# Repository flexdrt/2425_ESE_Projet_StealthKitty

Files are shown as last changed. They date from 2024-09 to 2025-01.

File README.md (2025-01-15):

# 🐱 **StealthKitty - Projet Robot Chat**  

 Logo ENSEA   
 
  

---

## 📜 **Description**  
StealthKitty est un projet de **système embarqué innovant** basé sur un **STM32**.  
🎯 **Objectif :** Développer plusieurs robots capables de se déplacer sur une table sans bordure.  

- 🐾 Un robot est désigné comme chat et doit attraper un autre robot, qui devient alors le nouveau chat.  

Ce projet est réalisé dans le cadre de la dernière année de la filière **électronique et systèmes embarqués (ESE)** de l'ENSEA.

### **Les contributeurs :**  
- 👨‍💻 **Vincent LAKHMECHE**  
- 👨‍💻 **Mohamed Rafik CHAIR**  
- 👨‍💻 **Meziane Ameur**  
- 👨‍💻 **Karim JERJOUB**

<p align="center">
  
</p>

---

## 📚 **Table des matières**
1. [📖 Contexte](#-contexte)
2. [📐 Architecture](#-architecture)  
3. [✨ Fonctionnalités](#-fonctionnalités)
4. [📚 Explication Technique](#-Explication-Technique). 
5. [🔧 Matériel utilisé](#-matériel-utilisé)  
6. [🚀 Utilisation](#-utilisation)  
7. [📄 Licence](#-licence)  

---

## 📖 **Contexte**  
Ce projet s'inscrit dans le cadre de la formation 3A à l'ENSEA.  
🎯 L'objectif est de concevoir un système embarqué complet, depuis la conception électronique jusqu'à l'implémentation logicielle.

---

## 📐 **Architecture**  
### **Schéma architectural**  


Ce schéma ne détaille pas que chaque moteur a sa propre pwm et son driver propre également.

## Explication du fonctionnement du système

1. **⚡ Alimentation principale**
   - La **batterie NiMH 7.2V 1.3Ah** alimente l'ensemble du système. Elle est connectée à des régulateurs de tension pour fournir les différentes tensions nécessaires aux composants :
     - **MP1475S** : Régulateur 5V pour alimenter les moteurs et certains capteurs.
     - **BU33SD5WG-TR** : Régulateur 3.3V pour alimenter le microcontrôleur STM32G431, l'accéléromètre et le LiDAR.

2. **🖥️ Microcontrôleur principal - STM32G431**
   - Le **STM32G431** gère toute la logique du robot et communique avec les différents composants via des bus tels que SPI, UART, I2C.
   - Il est relié à un **quartz 16 MHz** pour la gestion de l'horloge système et dispose d'un connecteur **SWD** pour la programmation et le débogage.

3. **🔍 Capteurs**
   - **Capteurs ToF** : Utilisés pour détecter les bords ou les chutes du robot.
   - **ADXL343 (Accéléromètre)** : Détecte les impacts ou les tapotements, utilisé pour détecter les collisions avec d'autres robots, et connecté au bus **SPI**.
   - **LiDAR YDLIDAR X4** : Permet de détecter les obstacles à l'aide de la communication **UART** pour transmettre les données de distance et d'angle.

4. **⚙️ Contrôle des moteurs**
   - **ZXBM5210-SP-13 (Driver de moteur)** : Utilisé pour contrôler la direction et la vitesse des moteurs à l'aide de signaux **PWM**. Le microcontrôleur STM32 contrôle les moteurs via le driver pour ajuster la vitesse et la direction du robot.

5. **🌟 Indicateurs d'état (LEDs)**
   - Les **LEDs** servent d'indicateurs pour visualiser l'état du robot, par exemple, lorsqu'il est en marche ou lorsqu'il détecte un obstacle.

### Détails des principaux outils utilisés

1. **Communication avec l'accéléromètre (ADXL343)**
   - Utilisation du protocole **SPI** pour lire les données des axes X, Y et Z.
   - Détection des chocs (taps) causés par des collisions avec d'autres robots.

2. **Contrôle des moteurs avec le driver ZXBM5210**
   - Génération de signaux **PWM** pour réguler la vitesse des moteurs.
   - Implémentation des mouvements du robot : avancer, reculer, tourner à gauche ou à droite.

3. **Gestion des capteurs de bordure/détection de chute**
   - Lecture des entrées des capteurs pour détecter les bords de la table.
   - Réaction immédiate pour stopper ou changer de direction afin d’éviter une chute.

4. **Interfaçage avec le LiDAR YDLIDAR X4**
   - Communication via **UART** pour lire les données du LiDAR ainsi détecter les autres robots.
   - Extraction des valeurs d’angles et de distances pour cartographier l'environnement et éviter les obstacles.

---

## ✨ **Fonctionnalités**  
- 🛡️ **Détection de bords** via des capteurs ToF.  
- 🔄 **Communication entre robots** pour synchronisation.  
- 🎯 **Algorithme de poursuite et d'évitement.**  
- ⚙️ **Gestion des moteurs**
  
## 📚 Explication Technique

#  ⚡Accéléromètre ADXL343 dans le robot chat

<details>
<summary> Détail  sur l'utilisation de l'accéléromètre ADXL343 </summary>

## 🎯 Objectifs principaux
- ✨ **Détecter les tapotements** (Single Tap/Double Tap) pour **changer de rôle** entre le robot dans l'état "chat" et dans l'état "souris".
- 📊 Lire les valeurs d'accélération sur les axes **X, Y, Z** *(optionnel)*.

---

## ⚙️ Configuration
- **Plage d'accélération :** ±2 g *(précision pour petits mouvements)*.
- **Registres utilisés :**  
  - 🛠️ `POWER_CTL` : Activer le mode mesure.  
  - 🎚️ `THRESH_TAP`, `DUR`, `INT_ENABLE` : Configurer les seuils et activer les interruptions pour les tapotements.  
  - 🖥️ `INT_SOURCE` : Vérifier les événements de tapotements.

---

## 🔧 Fonctionnalités implémentées
### ✅ Détection des tapotements
- 🔄 Vérifie les interruptions via le registre `INT_SOURCE`.
- 📍 Met à jour la variable globale `tap_detected` pour signaler un événement.

### ✅ Lecture des accélérations
- 📥 Récupération des valeurs brutes : `acc_rawX`, `acc_rawY`, `acc_rawZ`.
- 🔄 Conversion des valeurs en unités normalisées (*g*) via un facteur de calibration.

---

## 🔁 Réactions aux tapotements
- ⚡ **Interruptions activées** pour permettre une réaction en temps réel.
- 🔀 Chaque tapotement entraîne un **changement de comportement des moteurs** (ex. direction ou rôle).

---

## 🕒 FreeRTOS Task
- Création d'une tâche principale **`vTaskADX`** pour :  
  1️⃣ Lire les données d'accélération brutes et normalisées.  
  2️⃣ Vérifier les événements de tapotement.  
  3️⃣ Ajouter un délai pour réduire la charge CPU (`vTaskDelay`).

---

https://github.com/user-attachments/assets/b687c830-fabb-43c3-ac29-a924f9b9cf93

</details>

# 📡Capteur ToF VL53L1X pour détection des bords
<details>
<summary> Détail sur l'utilisation du capteur ToF VL53L1X pour la détection des bords </summary>

## 🌟 Caractéristiques techniques

- 📡 **Technologie :** ToF (Time of Flight)
- 🕐 **Plage de mesure :** 4 mm à 4 m (en mode longue distance)
- ⏳ **Budget temporel :** Configurable entre 15 ms et 500 ms
  - 15 ms : mode court pour une réactivité accrue
  - 500 ms : mode long pour une meilleure précision
- 🔄 **Mode de distance :**
  - Court (1,3 m max) : meilleure immunité au bruit ambiant
  - Long (4 m max) : portée étendue pour des environnements sombres
- 🌌 **Précision :** ±1% dans des conditions optimales (100 mm cible, reflectance 17%)
- 🔐 **Interface :** I²C (adresse par défaut : 0x52)
- 🕒 **Temps d'inter-mesure :** Configurable selon le budget temporel

---

## ⚙️ Initialisation et communication

### Interface

- Communication via le port **hi2c1**.
- Configuration par défaut :
  - Mode de distance : Long (`VL53L1__DISTANCE_MODE = 2`)
  - Budget temporel : 20 ms (`VL53L1__TIMING_BUDGET = 20`)
  - Période d'inter-mesure : 25 ms (budget + delta)

### Fonction d'initialisation

```c
uint8_t VL53L1__Init() {
    uint8_t status = 0;
    printf("Initialisation du capteur VL53L1X...\n");
    status |= VL53L1X_SensorInit(TOF_ADDR);
    if (status != 0) {
        printf("Erreur lors de l'initialisation du capteur !\n");
        return status;
    }
    status |= VL53L1X_SetDistanceMode(TOF_ADDR, VL53L1__DISTANCE_MODE);
    status |= VL53L1X_SetTimingBudgetInMs(TOF_ADDR, VL53L1__TIMING_BUDGET);
    status |= VL53L1X_SetInterMeasurementInMs(TOF_ADDR, VL53L1__INTERMEASUREMENT);
    printf("Capteur initialisé avec succès.\n");
    return status;
}
```

---

## 🔧 Traitement des données

1. **Acquisition des données :**
   - Utilisation de `VL53L1X_CheckForDataReady()` pour vérifier la disponibilité.
   - Récupération des distances avec `VL53L1X_GetDistance()`.
   - Mesure complétée en fonction du timing budget configuré.

2. **Filtrage et validation :**
   - Contrôle de `RangeStatus` pour éliminer les mesures aberrantes.
   - Comparaison avec des seuils définis pour rejeter les valeurs hors plage.

3. **Analyse :**
   - Calcul des distances moyennes et écart-type pour optimiser la précision.
   - Intégration avec les données des autres capteurs pour la prise de décision globale.

---

## 📊 Analyse et décisions

### Détection d'obstacles

- Un seuil critique est défini (é.g., 250 mm).
- Si la distance mesurée dépasse ce seuil, une action est entreprise pour éviter la collision et la chute avec le bord.
- Exemple de logique d'évitement : ralentir ou pivoter.

### Exemple : Pivot automatique

```c
if (distance > 250) {
    printf("Obstacle détecté : pivot en cours...\n");
    reverse_motors();  // Fonction pour inverser les moteurs
    vTaskDelay(pdMS_TO_TICKS(500)); // Pause pour effectuer le pivot
    forward_motors(); // Reprise de la trajectoire
}
```

---

## 💾 Structure de données

### Paramètres de configuration

```c
#define VL53L1__TIMING_BUDGET 20
#define VL53L1__DISTANCE_MODE 2
#define VL53L1__LOWER_THRESHOLD 0
#define VL53L1__UPPER_THRESHOLD 4000
```

### Stockage des résultats

```c
typedef struct {
    uint8_t Status;       // Statut de la mesure (erreurs incluses)
    uint16_t Distance;    // Distance mesurée en mm
    uint16_t SignalRate;  // Taux de signal en kcps
    uint16_t AmbientRate; // Taux de bruit ambiant
    uint16_t SpadNum;     // Nombre de SPADs actifs
} VL53L1X_Result_t;
```

---

## ↻ Cycle de fonctionnement

1. Initialisation du capteur ToF avec les paramètres prédéfinis.
2. Boucle d'acquisition des distances :
   - Vérification de l'état du capteur.
   - Lecture et validation des données mesurées.
   - Mise à jour des structures de données.
3. Filtrage des mesures aberrantes et analyse des distances.
4. Détection des obstacles et application des consignes aux moteurs.

---

## 🚀 FreeRTOS : Gestion du capteur ToF

### Exemple de tâche FreeRTOS

```c
void vTaskToF(void *argument) {
    uint16_t distance;
    uint8_t range_status;

    for (;;) {
        // Vérification de la disponibilité des données
        VL53L1X_CheckForDataReady(TOF_ADDR, &range_status);
        if (range_status == 0) {
            // Lecture de la distance
            VL53L1X_GetDistance(TOF_ADDR, &distance);
            printf("Distance mesurée : %d mm\n", distance);

            // Détection d'obstacle
            if (distance > 250) {
                printf("Obstacle détecté, exécution d'un pivot.\n");
                reverse_motors();
                vTaskDelay(pdMS_TO_TICKS(500));
                forward_motors();
            }
        }
        // Pause entre les mesures
        vTaskDelay(pdMS_TO_TICKS(100));
    }
}
```

### Gestion des ressources
- Synchronisation avec des **sémaphores** pour la gestion des interruptions.
- Utilisation de **timers FreeRTOS** pour des mesures périodiques précises.

### Points clés
- Priorité des tâches : la tâche de mesure ToF doit avoir une priorité suffisante pour garantir des mises à jour régulières.
- Gestion des erreurs : surveiller les `RangeStatus` pour éviter des comportements inattendus.

---

## 🛠️ Fonctions clés du driver

- `VL53L1X_SensorInit()` : Initialise le capteur avec les valeurs par défaut.
- `VL53L1X_GetDistance()` : Récupère la distance mesurée (mm).
- `VL53L1X_SetTimingBudgetInMs()` : Configure le budget temporel des mesures.
- `VL53L1X_ClearInterrupt()` : Réinitialise les interruptions après une mesure.
- `VL53L1X_SetDistanceMode()` : Change le mode de mesure (écourté ou étendu).

---

## ⚠️ Points critiques

- Gestion des interruptions I²C et des erreurs de communication.
  - Implémentation robuste pour minimiser les échecs de transfert.
- Calibration régulière pour minimiser les erreurs systématiques.
  - Offset et cross-talk à recalibrer selon l'environnement.
- Ajustement des seuils selon les conditions environnementales :
  - Température ambiante et réflectance des surfaces peuvent affecter les mesures.

https://github.com/user-attachments/assets/b8a1714b-683e-4680-be36-7b728edb92a1

</details>

# 🛠️Contrôle des Moteurs et Encodeurs

<details>
<summary> Détail sur le contrôle des Moteurs et sur les Encodeurs </summary>

## 🛠️ Composants utilisés

Les moteurs utilisés sont des motoréducteurs de la marque DFRobot, les modèles FIT 052X équipés d'un encodeur à quadrature.

Nos moteurs ont une vitesse différentes pour un même rapport cyclique, cependant la différence de vitesse varie en fonction des rapports cycliques choisis, nous n'avons pas pu compenser cette erreur de manière durable et fiable. 
Cela a aussi rendu plus complexe l'implémentation des asservisssements en vitesse et en angle qui devaient prendre en compte ce problème.

## 🚗 Moteurs

Le contrôle des moteurs est effectué à l'aide d'un driver. Ce driver contient plusieurs fonctions pour contrôler la direction et la vitesse des moteurs du robot.

### Fonctionnalités du driver :

- **`void init_motors(void);`** : Initialisation des moteurs.
- **`void forward_r(uint16_t alpha);`** : Faire avancer le moteur droit.
- **`void forward_l(uint16_t alpha);`** : Faire avancer le moteur gauche.
- **`void reverse_r(uint16_t alpha);`** : Faire reculer le moteur droit.
- **`void reverse_l(uint16_t alpha);`** : Faire reculer le moteur gauche.
- **`void stop_r(void);`** : Arrêter le moteur droit.
- **`void stop_l(void);`** : Arrêter le moteur gauche.

### 🔧 Considérations mécaniques

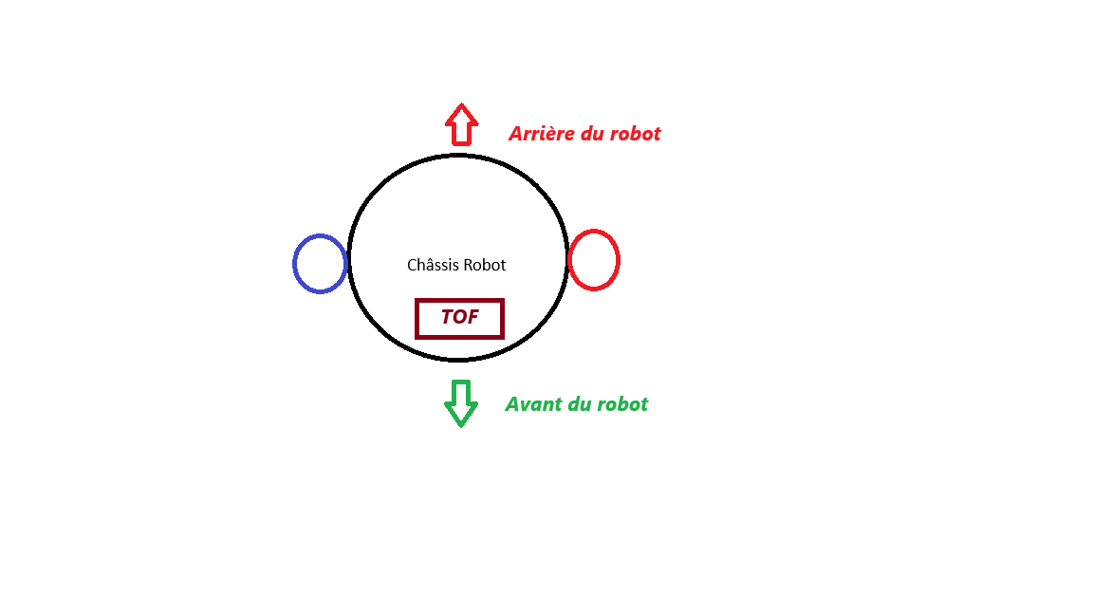
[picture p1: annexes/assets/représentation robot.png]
chassis Image 2025-01-13 à 14 57 42_cc206d9a


Le robot utilise deux moteurs, un pour chaque roue :

- La roue droite est en **rouge** et la roue gauche est en **bleue**.
- Les roues tournent dans des directions opposées pour permettre au robot de se déplacer en avant ou en arrière.

### 🔄 Sens de marche
aaa

| Moteur Gauche  | Sens de marche Robot | Moteur Droit |
| --- | --- | --- |
| Sens **reverse** | Sens **forward** | Sens **forward** |

Pour avoir le sens de marche du robot en arrière, le tableau est le même sauf que l'on change le sens de chaque moteur.

---

## 🚀 Fonctionnement des moteurs

### Mise en mouvement
- **Avancer** :
  - `forward_r(uint16_t alpha)` : Configure le moteur droit pour avancer en réglant le rapport cyclique PWM sur la valeur spécifiée par `alpha`. Cela contrôle la vitesse de rotation du moteur droit. **Point critique** : Assurez-vous que `alpha` reste dans les limites de la plage autorisée pour éviter de surcharger le moteur.
  - `forward_l(uint16_t alpha)` : Configure le moteur gauche pour avancer avec un fonctionnement similaire au moteur droit.

- **Reculer** :
  - `reverse_r(uint16_t alpha)` : Inverse la polarité pour le moteur droit afin qu'il recule. Le rapport cyclique PWM `alpha` détermine la vitesse en mode reverse. **Point critique** : La synchronisation entre les moteurs est essentielle pour un déplacement précis.
  - `reverse_l(uint16_t alpha)` : Applique le même principe pour le moteur gauche.

### Arrêt
- `stop_r()` : Arrête le moteur droit en mettant le signal PWM à zéro et en désactivant le canal PWM correspondant. **Point critique** : Un arrêt brusque peut endommager le système mécanique si des forces importantes sont en jeu.
- `stop_l()` : Arrête le moteur gauche de manière similaire pour immobiliser le robot.

---

## 🔧 Encodeurs
Les encodeurs mesurent la rotation des moteurs pour calculer leur position et leur vitesse. Ces données sont essentielles pour un contrôle précis. Un test en vidéo des encodeurs est visible plus haut dans ce document, dans la partie "Détail sur l'utilisation de l'accéléromètre ADXL343" (on peut voir la vitesse du moteur droit et gauche). 

### Fonctions principales
1. **Position** :
   - `get_encoder_position(uint8_t motor)` : Retourne la position actuelle en impulsions pour le moteur spécifié (gauche ou droit). Cette valeur est obtenue en lisant le compteur du timer associé à l'encodeur. **Point critique** : Une dérive dans les valeurs peut indiquer un problème de calibration ou de bruit.

2. **Réinitialisation** :
   - `reset_encoder(uint8_t motor)` : Réinitialise la valeur du compteur de l'encodeur à zéro, permettant de redémarrer les mesures à partir d'une référence claire. **Point critique** : Réinitialisez uniquement lorsque les moteurs sont à l'arrêt pour éviter des erreurs de mesure.

3. **Vitesse** :
   - `calculate_motor_speed(uint8_t motor, uint32_t delta_time_ms, uint16_t encoder_resolution)` : Calcule la vitesse en tours par seconde à partir des différences de positions mesurées par l'encodeur sur une durée spécifiée. La résolution de l'encodeur (en impulsions par tour) est utilisée pour la conversion. **Point critique** : Le choix d'un intervalle de temps trop court peut amplifier le bruit dans les calculs de vitesse.

---

## 🛠 Contrôle PID
Le contrôle PID ajuste dynamiquement la commande des moteurs pour maintenir une vitesse cible.

- `compute_pid(float target_speed, float measured_speed, float *integral_error, float *previous_error, float kp, float ki, float kd)` :
  - **Entrées** :
    - `target_speed` : La vitesse souhaitée pour le moteur.
    - `measured_speed` : La vitesse réelle mesurée par l'encodeur.
    - `integral_error` : Accumulation des erreurs précédentes pour l'effet intégral.
    - `previous_error` : Dernière erreur enregistrée pour l'effet dérivé.
    - `kp`, `ki`, `kd` : Gains proportionnel, intégral et dérivé.
  - **Sortie** :
    - Une commande ajustée à appliquer au moteur pour corriger l'écart entre la vitesse cible et mesurée. **Point critique** : Un mauvais réglage des gains PID peut entraîner des oscillations ou une réponse lente.

---

## 🛠 Modes de fonctionnement

### Mode "Souris"
- **Objectif** : Déplacement à vitesse modérée.
- Les fonctions `forward_r()` et `forward_l()` configurent les moteurs pour avancer avec un rapport cyclique moyen (environ 40%).
- La vitesse et la position de chaque moteur sont mesurées et affichées périodiquement.
- Ce mode est conçu pour une navigation fluide et contrôlée. **Point critique** : Surveiller les variations de vitesse pour éviter les dérapages.

### Mode "Prédateur"
- **Objectif** : Déplacement rapide pour des actions dynamiques.
- Les moteurs fonctionnent à un rapport cyclique plus élevé (environ 70-80%).
- Ce mode est idéal pour des courses ou des approches agressives nécessitant une réponse rapide. **Point critique** : Les moteurs peuvent surchauffer si le mode est utilisé trop longtemps sans pauses.

### Pivot Arrière
- **Objectif** : Éviter les obstacles en pivotant.
- Les moteurs sont commandés pour reculer à des vitesses différentes, créant une rotation du robot.
- Exemple : Le moteur droit recule rapidement tandis que le gauche recule lentement, produisant une rotation autour d'un axe.
- Après le pivot, les moteurs reprennent leur fonctionnement normal. **Point critique** : Assurez-vous que le sol offre suffisamment d'adhérence pour un pivot efficace.

---

## 💡 Notes Techniques
- **Timers** :
  - TIM1 : Gère les signaux PWM pour le contrôle des moteurs.
  - TIM3 : Utilisé pour l'encodeur du moteur droit.
  - TIM4 : Utilisé pour l'encodeur du moteur gauche.

- **Résolution** :
  - Les encodeurs ont une résolution de 1024 impulsions par tour, ce qui offre une précision élevée pour les mesures de position et de vitesse.

- **Rapports Cycliques** :
  - La valeur `alpha` utilisée dans les fonctions correspond au rapport cyclique du signal PWM. Un rapport plus élevé entraîne une vitesse de rotation plus importante. **Point critique** : Vérifiez que le matériel supporte la plage de fonctionnement du PWM pour éviter des dommages.
 
</details>

#  🚀YDLIDAR X4 dans le robot

<details>
<summary> Détail sur l'utilisation du YDLIDAR X4 dans le robot  </summary>

**🎯 Caractéristiques techniques**
* 📡 **Range Frequency :** 5000Hz
* 📏 **Range Distance :** 0.12-10m 
* 📐 **Angle Resolution :** 0.43-0.86°
* 🔄 **Scan Frequency :** 6-12Hz
* 🌟 **Scan Angle :** 360°
* 📦 **Size :** Φ65.6 * 58.39 * 101.7mm

**⚙️ Communication et trames**
* 🔌 **Interface :** UART (DMA)
* 📦 **Structure des trames :**
  * 🏁 Start Sign : 0xA5 0x5A
  * 📊 Package Length
  * 🔍 Mode & Type Code
  * 📐 FSA (First Scan Angle)
  * 📐 LSA (Last Scan Angle)
  * ✅ CS (Checksum)
  * 📝 Packet Data

**🔧 Traitement des données**
* **Parser de trames :**
Le parsing suit la datasheet du Lidar et est détaillé au sein de la tache TaskLidar.

**📊 Analyse des données**
* 🔍 **Détection d'objets :**
  * Filtrage des distances (0-2000mm)
  * Calcul des centres de masse (assimilable à  du clustering de points par paquets)
  * Identification des clusters
* 🎯 **Tracking :**
  * Suivi de l'objet le plus proche
  * Calcul angle moyen et distance

------

**⚡ Performances**
* 🔄 **Temps réel :** Acquisition et traitement via DMA pour ne pas saturé la RAM
* 📊 **Résolution :** ~0.5° en rotation
* 📏 **Précision distance :** ±1% sur plage optimale
* ⏱️ **Latence :** <100ms pour détection et réaction(idéalement)

**🔁 Cycle de fonctionnement**
1. 📡 Réception trame DMA
2. 🔍 Validation checksum et headers
3. 📊 Parsing des données
4. 🎯 Détection objets et calcul distances
5. 🎮 Application asservissement moteurs vu ultérieurement

**🛠️ Fonctions clés du driver**
```c
sns_begin()        // Démarrage acquisition
sns_parse_data()   // Traitement trame
smooth_data()      // Filtrage données
detect_objects()   // Détection objets
```

**⚠️ Points critiques**
* Gestion buffer circulaire DMA
* Validation intégrité trames
* Filtrage données aberrantes
* Asservissement progressif détaillé ultérieurement

## 🕒 FreeRTOS Task du LIDAR

- ## 📦 Détection et Validation En-tête (i==0)

  - Vérification séquence 7 octets :

    - 0xA5 0x5A (Start Sign)
    - 0x05 0x00
    - 0x00 0x40
    - 0x81

  ## 📝 Parsing de Trame (Machine à États)

  - frame_start : Package Header bas
  - frame_start+1 : Package Header haut
  - frame_start+2 : Type de paquet
  - frame_start+3 : Nombre d'échantillons
  - frame_start+4/5 : Angle de début (FSA)
  - frame_start+6/7 : Angle de fin (LSA)
  - frame_start+8/9 : Checksum

  ## 🎯 Traitement des Données

  - Si fin de trame (i==frame_end) :

    - Stockage dernière donnée
    - Parse des données brutes
    - Lissage des données
    - Détection des objets
    - Reset des index pour trame suivante

  ## 📊 Analyse Finale

  - Recherche de l'objet le plus proche :

    - Distance minimale non nulle
    - Mise à jour dist_min et idx_min

<p align="center">
 
</p>

  - Affichage données :

    - Pour chaque objet : angle et distance
    - Détails de l'objet le plus proche

  ## ⚙️ Gestion des Indices

  - Ajustement frame_start et frame_end
  - Gestion du buffer circulaire
  - Maintien de la synchronisation des trames

Dans la vidéo suivante un test est réalisé avec un script python pour mieux visualiser les donnés reçus, on remarque une légère latence pour que les données soient affichés et des outliers.

https://github.com/user-attachments/assets/c904982a-7dda-46ab-8d87-f73b21fb672f

</details>

# 🎯Théorie de l'asservissement angulaire du robot

<details>
<summary> Détail sur la théorie de l'asservissement angulaire du robot  </summary>

## 1. Définition du système

### Variables d'état
- θ_mesure : Angle mesuré par le LIDAR du cluster le plus proche (en degrés)
- θ_consigne : Angle désiré (0° dans notre cas)
- e(t) : Erreur en angle
- u(t) : Signal de commande (correction)
- v_g : Vitesse du moteur gauche
- v_d : Vitesse du moteur droit

### Équations fondamentales

1. Calcul de l'erreur :
```
e(t) = θ_consigne - θ_mesure
```

2. Loi de commande proportionnelle :
```
u(t) = Kp × e(t)
```
où Kp est le gain proportionnel

3. Vitesses des moteurs :
```
v_g = v_base + u(t)
v_d = v_base - u(t)
```
où v_base est la vitesse nominale

## 2. Normalisation de l'angle

Pour avoir un comportement symétrique, l'angle mesuré est normalisé dans l'intervalle [-180°, 180°] :
```
Si θ_mesure > 180° :
    θ_normalisé = θ_mesure - 360°
Sinon :
    θ_normalisé = θ_mesure
```

## 3. Fonction de transfert

Dans le domaine de Laplace, la fonction de transfert du système peut être approximée par :

```
G(s) = K / (1 + τs)
```
où :
- K est le gain statique du système
- τ est la constante de temps du système
- s est la variable de Laplace

## 4. Stabilité du système

Le système en boucle fermée a une fonction de transfert :
```
H(s) = (K × Kp) / (1 + τs + K × Kp)
```

La stabilité est assurée si :
```
0 < Kp < 1/(K × τ)
```

## 5. Considérations de mise en œuvre

1. Choix du gain Kp :
- Trop faible : réponse lente
- Trop élevé : oscillations
- Optimal : compromis entre rapidité et stabilité

**Conversion en commandes moteurs** (alpha1 et alpha2) :

- Si la cible est à droite :

  - On augmente la vitesse du moteur gauche (alpha1)

  - On diminue la vitesse du moteur droit (alpha2)

    → Le robot tourne à droite

- Si la cible est à gauche :

  - On augmente la vitesse du moteur droit (alpha2)

  - On diminue la vitesse du moteur gauche (alpha1)

    → Le robot tourne à gauche

A défaut d'un fonctionnement asservi en vitesse de nos moteurs, nous n'avons pas pu tester cet asservissement angulaire sur notre robot bien qu'une ébauche du code soit implémentée dans la tache du Lidar TaskLIDAR.
</details>

## 🔧 **Matériel utilisé**  
- **STM32G431CBU6** : Microcontrôleur principal.  
- **Capteurs ToF** : Détection des bordures.  
- **LiDAR** : Cartographie et détection d'autres robots.  
- **Accéléromètre (ADXL343)** : Détection des chocs pour changer de rôle (Chat/Souris).  
- **Environnement de développement :** STM32CubeIDE.  

---

## 🚀 **Réalisation matérielle**  
La partie matérielle a été conçue avec **KiCad 8.0** et comprend :  

- 📜 **Schéma électronique**

<details>
<summary> Détail sur le schéma électronique </summary>

Pour construire notre carte électronique, il nous a fallut commencer par designer sous KiCad le schéma électrique de notre système électronique, ce que l'on appelle schematic dans KiCad. Nous allons maintenant détaillé les différentes parties du schematic (les sheets du projet KiCad).

## Schéma électronique ## 
#### Capteurs du robot #####

Le robot contient plusieurs capteurs, un capteur Time Of Flight TOF, un capteur LIDAR, et un capteur accéléromètre.

Le capteur TOF est un capteur de distance qui communique en I2C avec le cerveau du robot qu'est le stm32. L'avantage de cette communication est qu'elle permet une évolutivité si le besoin d'ajouter d'autres composants matériel par la suite se fait sentir (c'est pourquoi on a prévu des résistances de pull-up pour le bus I2C). Ce n'était pas notre cas, un seul capteur a suffit finalement. 

Ces signaux sont représentés sur le connecteur JST de la figure ci-dessous.

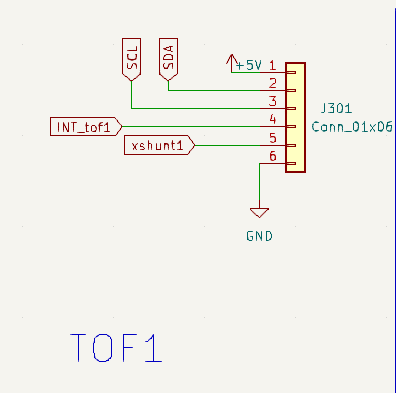
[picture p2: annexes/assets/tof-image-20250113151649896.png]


Le capteur Accéléromètre est le seul capteur qui communique en SPI.

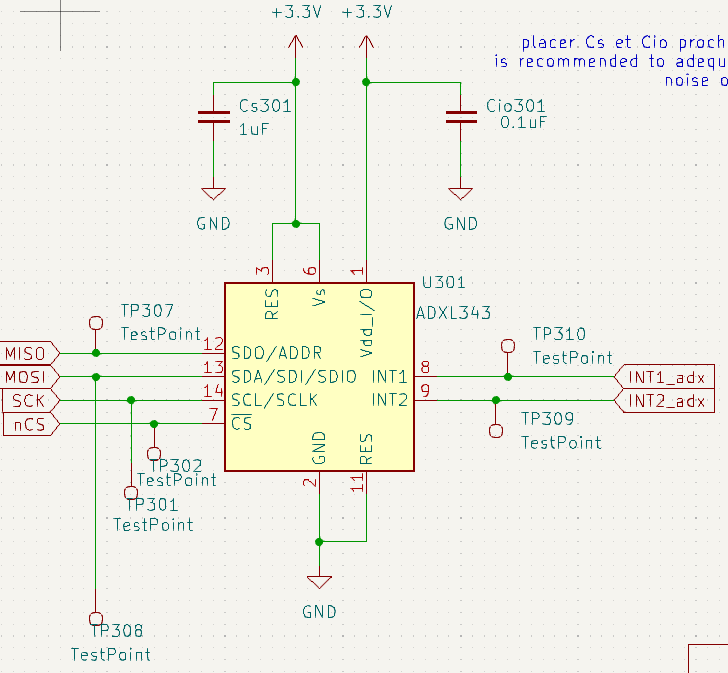
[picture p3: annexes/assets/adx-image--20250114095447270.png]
 

Comme on peut le voir, pour des raisons CEM nous avons placé une capacité de 1µF et une capacité de 0.1 µF pour découpler les deux alimentations en +3.3V.

Afin de pouvoir débugger le capteur, nous avons également placé des points de test TestPoint.

Le capteur LIDAR est un capteur qui communique par liason série UART dont les signaux sont les suivants :

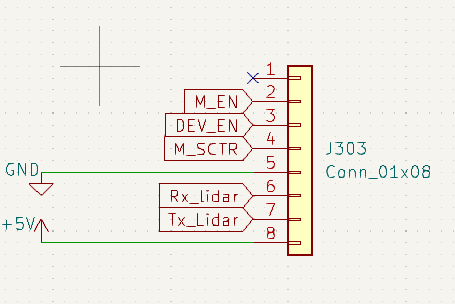
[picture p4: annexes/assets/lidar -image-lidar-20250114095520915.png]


- M_EN
- DEV_EN
- M_SCTR
- RX_lidar
- TX_lidar
- +5V
- GND

#### Motorisation du robot ####

Les composants qui s'assure déplacer le robot sont les moteurs qui sont des mcc **FIT 0520.** 

Pour commander ces moteurs nous avons besoin de driver, ce sont eux qui vont envoyer les signaux de commande au moteur (des PWM). 

Les drivers utilisés sont les ZXBM5210-S-13. 

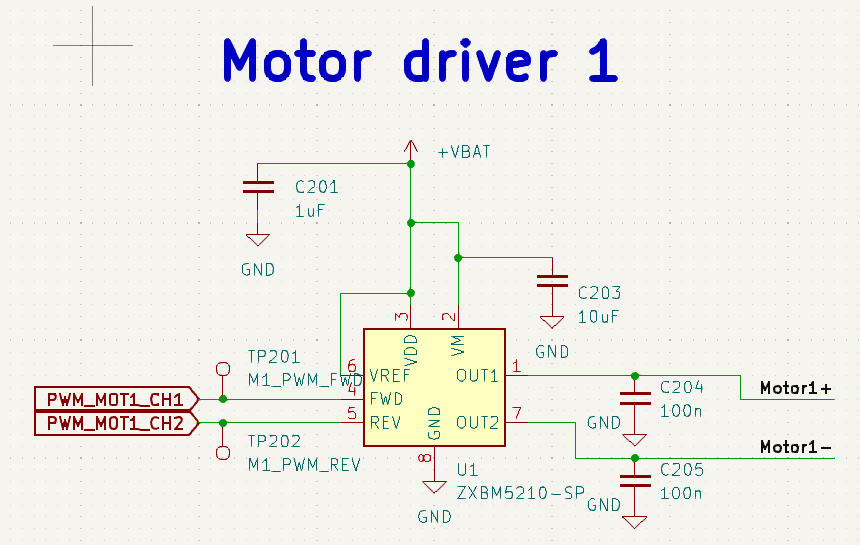
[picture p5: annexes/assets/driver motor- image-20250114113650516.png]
image-driver20250114113650516


Voici le schéma du composant. Les sorties out 1 et out 2  sont connectés au moteur par Motor1+ et  Motor 1-.

Comme ce sont les signaux de commande PWM, nous avons découplé ces signaux avec des capacités de 100nF.

Quant aux signaux d'alimentation, nous découplons la tension de la batterie avec une capacité de 10 µF pour le signal Vm et une capacité de 1µF pour la tension VBAT.

Le signal PWM_MOT1_CH1 est le signal PWM généré par le STM32 en direction du pin FWD du composant.
Le signal PWM_MOT1_CH2 est le signal PWM généré par le STM32  en direction du pin REV du composant.

D'après le tableau de la datasheet, si on envoie un signal PWM pour contrôler le driver en mode "PWM control mode". 

Il faut alors envoyer un signal PWM en entré sur un des pins FWD ou REV. Ce qui donnera naissance à un signal PWM en sortie de fréquence égale à celle en entrée du pin qui reçoit le signal PWM.   
Comme nous avons deux moteurs, il faut deux drivers, voici le schéma du deuxième driver : 
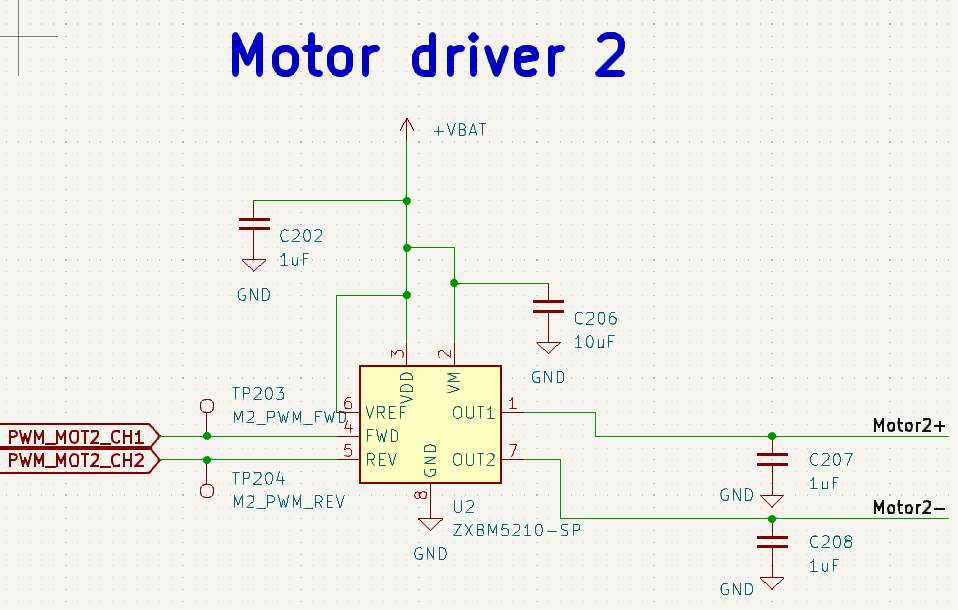
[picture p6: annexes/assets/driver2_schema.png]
driver2


Pour obtenir la vitesse des roues, nous utilisons les encodeurs des moteurs. Pour cela il faut préparer, l'alimentation et les signaux dont ils ont besoin dans un connecteur (jst en l'occurrence).

D'après la documentation des moteur/encodeurs, les signaux sont placés de la façon suivante sur le brochage : 

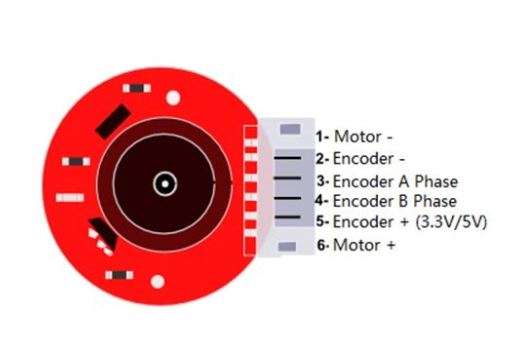
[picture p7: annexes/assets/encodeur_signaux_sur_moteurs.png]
signaux encodeurs


On peut lire sur cette image que les signaux de l'encodeur sont les suivants : 
 - +3V3
 - GND
 - codeurX_PH1 [pour la phase A]
 - codeurX_PH2 [pour la phase B]

Nous avons placé ces signaux, entre les deux signaux destinés au moteurs, et conservé l'ordre d'affectation des broches de la documention, ce qui donne ce schéma de connecteur : 

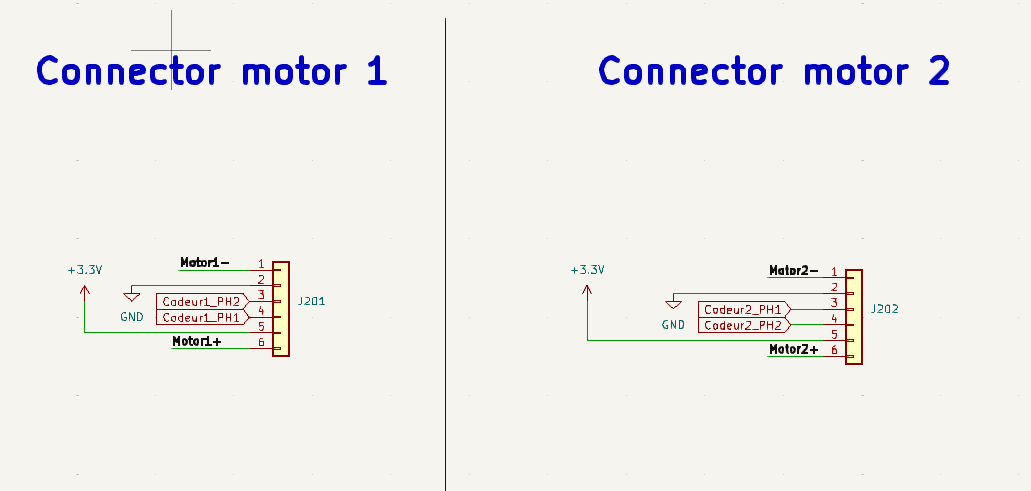
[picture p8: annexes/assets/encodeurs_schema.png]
encodeurs


#### Le Cerveau du robot : le STM32 & cie #### 

Dans cette feuille, nous avons connecté les composants suivants, le STM32, la STlink, le quartz, des leds, un bouton pour changer d'état et un bouton NRST pour reset le STM32.
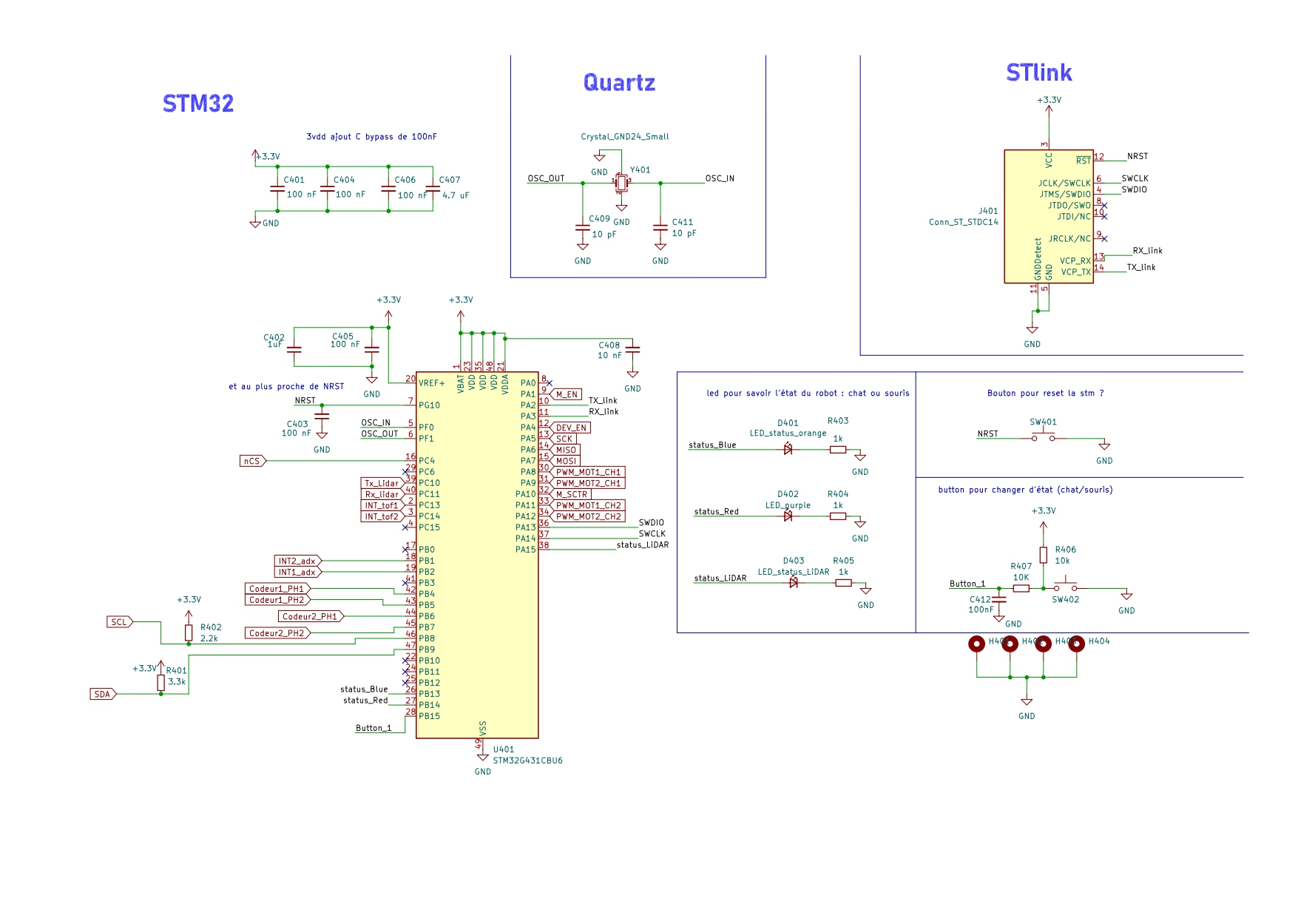
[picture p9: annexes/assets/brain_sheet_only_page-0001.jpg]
brain_sheet
  

 #####  Le STM32  #####

###### Explications assignations des signaux aux pins du STM32 ######
Pour assigner les pins du STM32, nous avons positionné d'abord les signaux PWM sur le timer 1, puis ceux des encodeurs. Les encodeurs, qui fonctionnent à une fréquence plus basse que les signaux PWM, ont besoin de leurs propre timer (le timer 3) configurés en mode "encoder mode".  
Ensuite nous avons connecté les signaux restant : 
 - l'USART4 du LIDAR (et ses connectiques)
 - l'USART2 du STLINK.
 - les signaux SPI pour l'accéléromètre
 - les signaux I2C du capteur TOF.   

Nous avons ajouté une résistance de pull-up sur le signal SDA et SCL respectivement de 3.3 kOhms et 2.2 kOhms  

###### Découplage du STM32 ######
Lors des transitions rapides des circuits internes du microcontrôleur, comme celles générées par les horloges et les commutations d’état des broches, des variations soudaines de courant peuvent se produire. Ces fluctuations génèrent des perturbations haute fréquence qui risquent de déstabiliser l'alimentation. 
Les condensateurs de 100 nF, placés aussi près que possible des broches d'alimentation (VDD, VDDA), jouent un rôle important en filtrant ces perturbations haute fréquence, agissant ainsi comme un réservoir d'énergie pour combler les besoins instantanés.

Pour stabiliser davantage l’alimentation, un condensateur de capacité plus élevée, comme un 4,7 µF, est ajouté. Celui-ci répond aux variations de courant plus lentes et de plus grande amplitude.
Par ailleurs, des broches spécifiques comme VDDA et VREF+, utilisées pour des fonctions sensibles telles que les convertisseurs analogiques-numériques (ADC), exigent une alimentation particulièrement propre. Un condensateur de 1 µF y est ajouté pour découpler VREF+ tandis qu'un condensateur de 10 nF découple VDDA.

Ainsi, la combinaison de condensateurs de différentes valeurs, placés stratégiquement près des broches concernées, permet de garantir la stabilité et la fiabilité du microcontrôleur STM32 tout en réduisant les effets des perturbations électriques.

##### 🕒  Le quartz #####
Le quartz fonctionne avec des niveaux de signaux très précis pour maintenir une oscillation stable. Sans découplage capacitif, les variations de tension peuvent causer des décalages de phase ou des changements de fréquence. Le condensateur agit comme un filtre passif, en éliminant les hautes fréquences parasites et en assurant une meilleure stabilité du signal.

Les signaux électriques OSC_In et OSC_OUT peuvent parfois inclure des pics de tension ou des variations transitoires. Un découplage capacitif agit comme une barrière, protégeant le quartz de ces stress électriques, augmentant ainsi sa durée de vie.
La valeur de la capacité de découplage est 10 pF pour l'entrée et 10pF pour la sortie du quartz.
En résumé, le découplage par une capacité assure une meilleure isolation, stabilité, et performance du circuit oscillateur. 

##### 🔗 Le STLink #####
La ST-Link est un outil nécessaire pour la gestion et le développement des microprocesseurs STM32. Elle remplit deux fonctions principales : la programmation du microprocesseur, en permettant de flasher le code directement sur celui-ci, et le débogage, grâce à une interface de communication série dédiée.

En bref, la ST-Link établit un lien direct entre l’environnement de développement et le STM32, simplifiant le processus de programmation et assurant une prise en charge efficace du débogage.

#####  Les boutons #####
Le PCB est consituté de deux boutons : le premier NRST sert à reset le code qui a été téléversé sur la carte. Le deuxième permet au robot de changer d'état entre souris et chat. 

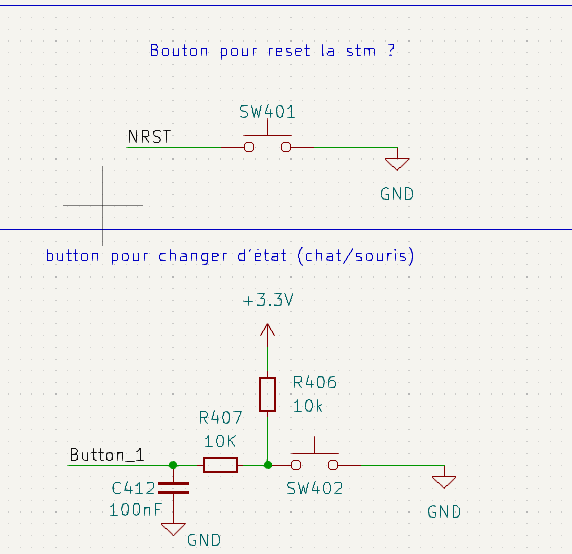
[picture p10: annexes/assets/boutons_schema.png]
boutons


##### 💡 Les LEDS #####
Les leds servent d'indicateurs pour visualiser l'état du robot, il y a une led bleue et une led rouge.

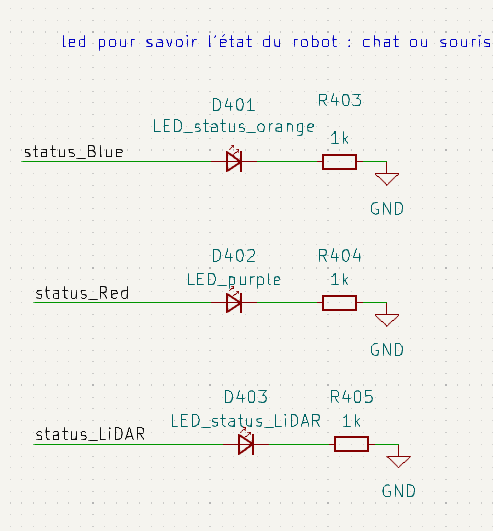
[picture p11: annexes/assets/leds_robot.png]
leds


Alimentation et Gestion d'Énergie :

- Le système est alimenté par une batterie  avec un switch ON/OFF  qui permet deux modes :
  1. Mode charge : Lorsque le chargeur est connecté, la batterie se recharge
  2. Mode fonctionnement : Alimentation du robot
- Un circuit de conversion de tension à plusieurs étages :
  - 7,2V (batterie) → 5V/3A via MP1475DJ-LF-P
  - 5V → 3.3V/150mA via BU33SD5WG-TR

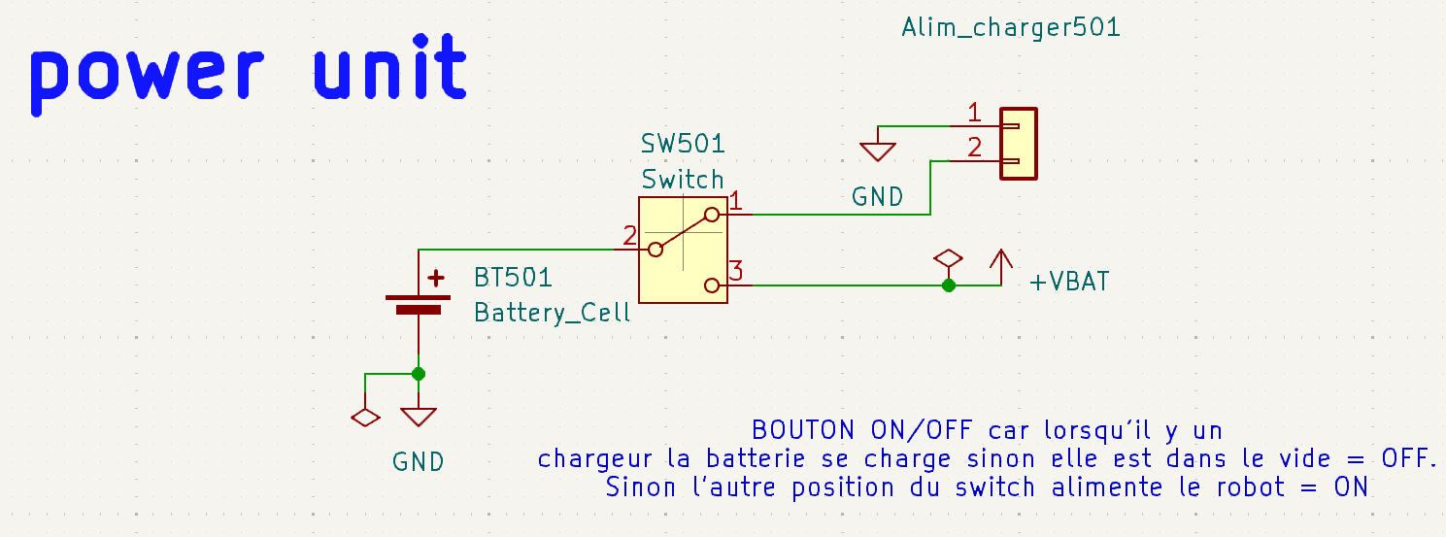
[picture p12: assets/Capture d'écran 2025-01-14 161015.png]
Capture d'écran 2025-01-14 161015


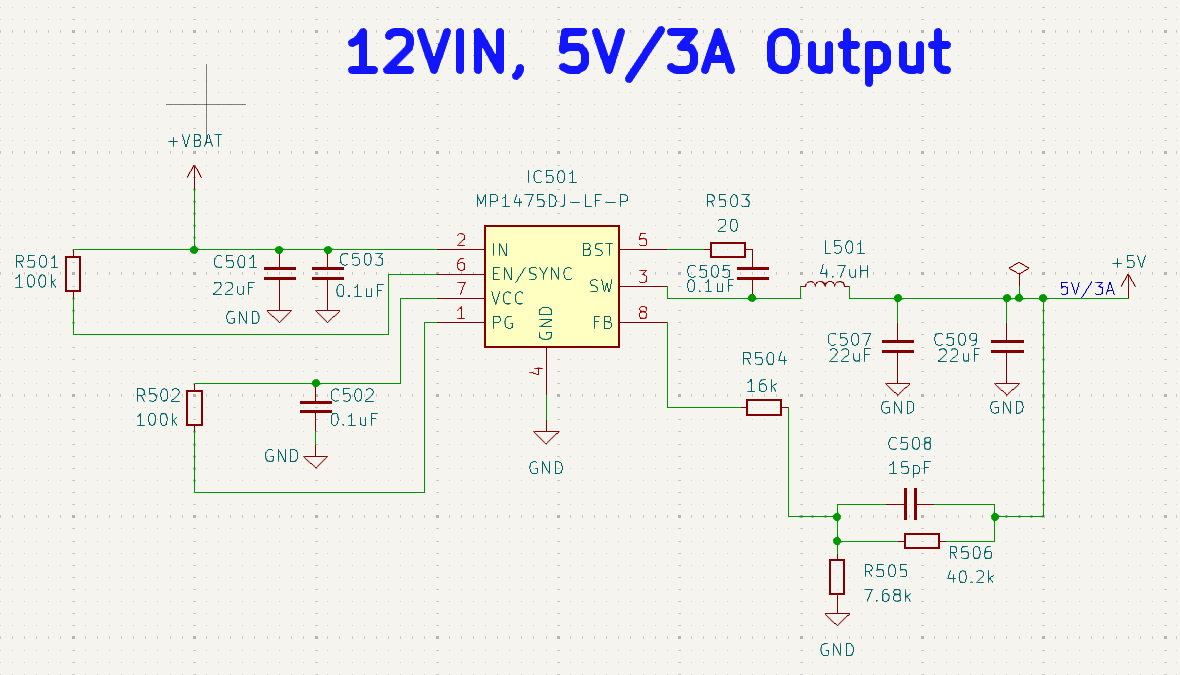
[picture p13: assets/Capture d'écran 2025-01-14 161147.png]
Capture d'écran 2025-01-14 161147


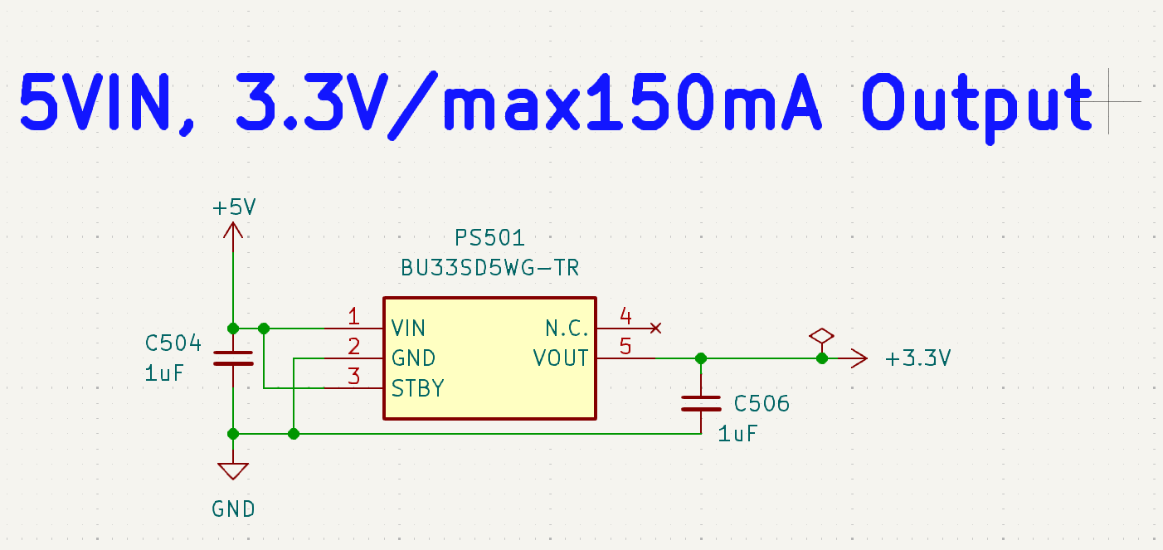
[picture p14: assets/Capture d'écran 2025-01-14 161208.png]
Capture d'écran 2025-01-14 161208


Points d'Attention :

1. Pour la partie alimentation :

- Respecter la polarité de la batterie
- Les condensateurs de filtrage sont essentiels pour stabiliser l'alimentation
- Les soudures du switch, point critique de fiabilité

1. Pour le convertisseur 7,2V→5V :

- La self 4.7µH doit supporter le courant nominal de 3A
- Le placement des condensateurs doit être proche du régulateur
- Le réseau de feedback doit être précis pour maintenir la tension de sortie

1. Pour le convertisseur 5V→3.3V :

- Les condensateurs C504 et C506 sont critiques pour la stabilité
- Le pin STBY doit être correctement connecté pour le fonctionnement

</details>

- 🧩 **PCB routé**

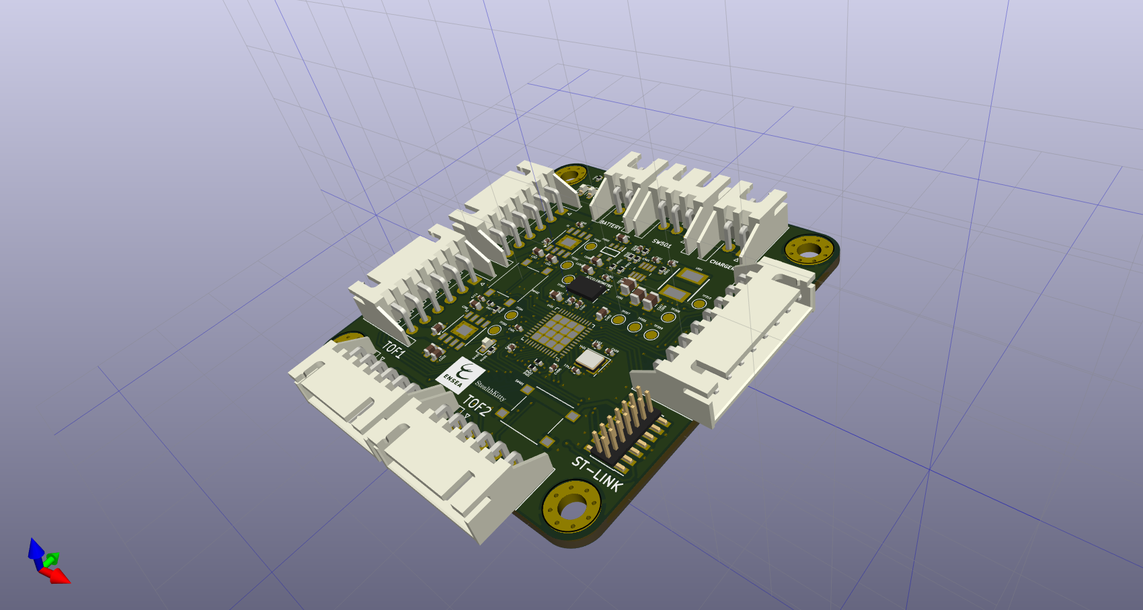
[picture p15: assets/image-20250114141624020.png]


<details>
<summary> Détail sur le routage du PCB </summary>

Le PCB à été conçu afin de respecter le cahier des charges en termes de dimension afin de pouvoir l'intégrer facilement au robot.

Capture d'écran 2025-01-15 002802

---

### Répartition des couches du PCB
1. **Couche 1 (Front)** : Support de tous nos composants, majoritairement CMS, avec des connecteurs traversants. La majorité des pistes y sont tracées également sur cette couche, tandis qu’une partie passe par la couche 4 (bottom) pour préserver l’homogénéité des plans de masse (couche 2) et d’alimentation (couche 3).
2. **Couche 2** : Plan de masse, avec des vias espacés pour éviter les coupures.  
3. **Couche 3** : Plan d’alimentation pour les composants à forte consommation, optimisant la dissipation thermique.  
4. **Couche 4 (Bottom)** : On retrouve les pistes de données issues principalement de la couche 1 pour garder l'intégrité des signaux. Nous avons également évité de croiser les discontinuités des plans d'alimentation (couche 3).

---

### Optimisations de routage

#### 1. Positionnement des Vias
Les vias ont été placés **aussi proches que possible des pastilles** des composants.

via tout prés possible des pastille

Cela minimise la longueur des connexions, réduisant ainsi les résistances parasites et améliorant la qualité des signaux.

---

#### 2. Protection du Quartz
Un **mur de vias** entoure l’oscillateur externe pour le protéger des **interférences électromagnétiques**.

protection du quartz par des via

Cette isolation réduit le risque de perturbations provenant des autres composants de la carte.

---

#### 3. Réduction des Problèmes d’Antenne
Des vias ont été placés dans les zones où des **antennes indésirables** pourraient se former.

probleme antenne

 Cela aide à minimiser les effets d’induction et les émissions parasites.

---

#### 4. Zones pour Signaux Importants
Des **plans dédiés** ont été créés pour les signaux importants.

zone de plan signaux important

Exemple pour le signal Motor+ qui a son propre plan pour assurer une transmission stable et fiable, réduisant les pertes et les perturbations.

---

#### 5. Plans d’Alimentation
##### a. Plan 5V
plan 5v

##### b. Plan VBAT
plan vbat

Les plans d’alimentation, tels que 5V et VBAT, ont été placés dans la couche 3 de la carte. Cela permet une meilleure répartition du courant et une connexion optimale aux composants qui nécessitent ces alimentations.

---

#### 6. Dissipation Thermique
Des **vias thermiques** ont été ajoutés pour améliorer la dissipation thermique.

des via pour des composant avec grande surface pour une meilleur dissipation

Cette pratique concerne des composants contenant des pads thermiques tels que le STM32 et les drivers des moteurs. Ces vias facilitent le transfert de chaleur vers d’autres couches, améliorant la dissipation thermique et empêchant les surchauffes.

---

#### 7. Condensateurs de Découplage
Les **condensateurs de découplage** ont été positionnés **au plus près des broches d’alimentation (ex. STM32, drivers)**.

capa decouplage a coté des alim

Cela réduit les parasites haute fréquence et stabilise l’alimentation.

---

#### 8. Adaptation des Pistes
La largeur des pistes a été ajustée pour correspondre aux pastilles des composants.

piste a la largeur des

Cela améliore la transmission des signaux et réduit les impédances parasites.

---

#### 9. Points de Test
Des **points de test accessibles** ont été placés pour faciliter le débogage.

de points de tests pour edbuggage

</details>

- 🛠️ **BOM (Bill of Materials)**  
- 🗂️ **Fichiers GERBER** pour fabrication chez **JLCPCB**.  

### 🔑 [Accédez aux fichiers hardware ici.](./hardware/)

---

## 🛠️ **Développement logiciel**  
Le logiciel embarqué a été développé avec **STM32CubeIDE** et inclut :  
- 🔧 **Configuration des périphériques** (SPI, UART, PWM, etc.).  
- 📦 **Modules logiciels** pour capteurs et moteurs.  
- 🤖 **Algorithmes embarqués** pour les comportements du robot (poursuite, évitement, etc.).  

### 📂 [Accédez au code source ici.](./firmware/)

### 📂 [Accédez à la documentation Doxygen ici.](./Doxygen/)

---

## 🎯 État des Fonctionnalités du Robot StealthKitty

### 🚗 Déplacement de Base

- ✅ Déplacement avant/arrière

- ✅ Rotation sur place

- ✅ Contrôle indépendant des moteurs

- ✅ Lecture des encodeurs

- 🟡 Asservissement en vitesse des moteurs

  > *Fonctionnel mais nécessite des optimisations pour plus de précision*

### 🛡️ Sécurité Anti-Chute

- ✅ Détection des bords via capteur ToF

- ✅ Arrêt automatique en cas de détection de vide

- ✅ Pivot arrière automatique(manœuvre d'évitement)

  > *Testé et validé sur table sans bordure comme visible sur vidéo*

### 👁️ Détection et Tracking

- ✅ Scan LIDAR 

- ✅ Détection des autres robots

- 🟡 Suivi de cible

  > Asservissement angulaire pas terminé et lecture du Lidar à améliorer

### 🎮 Modes de Jeu

- ✅ Changement de rôle via accéléromètre

- ✅ Mode "Chat" (prédateur), avec une vitesse augmentée

- ✅ Mode "Souris" (proie)

- 🟡 Algorithme de poursuite

  > *Base implémentée, work in progress*

### ⚡ Gestion Énergie

- ✅ Alimentation par batterie
- ✅ Protection contre la décharge
- ✅ LED d'état batterie

---

## 🏁 **Conclusion**  

Pour conclure, ce projet nous a permis de mettre en pratique et d'approfondir nos connaissances en électronique et systèmes embarqués. 

La réalisation de StealthKitty, de la conception du PCB à l'implémentation du firmware, nous a confrontés aux défis concrets de l'ingénierie : optimisation CEM, conception de cartes multicouches, intégration de capteurs et développement d'algorithmes de contrôle en temps réel. 

Cette expérience pratique a été formatrice, a renforcé notre compréhension des systèmes embarqués et nous a préparés aux futures exigences du monde professionnel.

WhatsApp Image 2025-01-15 at 17 13 14

---

## 📄 **Licence**  
📝 Ce projet est sous licence **MIT**.  
Pour plus d’informations, consultez le fichier [LICENSE](./LICENSE).

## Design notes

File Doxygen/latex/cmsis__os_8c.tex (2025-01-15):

\doxysection{Référence du fichier cmsis\+\_\+os.\+c}
\hypertarget{cmsis__os_8c}{}\label{cmsis__os_8c}\index{cmsis\_os.c@{cmsis\_os.c}}
{\ttfamily \#include $<$string.\+h$>$}\newline
{\ttfamily \#include "{}cmsis\+\_\+os.\+h"{}}\newline
\doxysubsubsection*{Structures de données}
\begin{DoxyCompactItemize}
\item 
struct \mbox{\hyperlink{structos__pool__cb}{os\+\_\+pool\+\_\+cb}}
\item 
struct \mbox{\hyperlink{structos__mail_q__cb}{os\+\_\+mail\+Q\+\_\+cb}}
\end{DoxyCompactItemize}
\doxysubsubsection*{Définitions de type}
\begin{DoxyCompactItemize}
\item 
typedef struct \mbox{\hyperlink{structos__pool__cb}{os\+\_\+pool\+\_\+cb}} \mbox{\hyperlink{cmsis__os_8c_a5843b92c9bd46a1c4f0de680a56537f4}{os\+\_\+pool\+\_\+cb\+\_\+t}}
\item 
typedef struct \mbox{\hyperlink{structos__mail_q__cb}{os\+\_\+mail\+Q\+\_\+cb}} \mbox{\hyperlink{cmsis__os_8c_a5afb33e919c9d492d5033933b33179d7}{os\+\_\+mail\+Q\+\_\+cb\+\_\+t}}
\end{DoxyCompactItemize}
\doxysubsubsection*{Fonctions}
\begin{DoxyCompactItemize}
\item 
void \mbox{\hyperlink{cmsis__os_8c_a78100b2d36913d0b45565be8975e5de8}{x\+Port\+Sys\+Tick\+Handler}} (void)
\item 
\mbox{\hyperlink{cmsis__os_8h_ae2e091fefc4c767117727bd5aba4d99e}{os\+Status}} \mbox{\hyperlink{cmsis__os_8c_a53d078a801022e202e8115c083ece68e}{os\+Kernel\+Initialize}} (void)
\begin{DoxyCompactList}\small\item\em Initialize the RTOS Kernel for creating objects. \end{DoxyCompactList}\item 
\mbox{\hyperlink{cmsis__os_8h_ae2e091fefc4c767117727bd5aba4d99e}{os\+Status}} \mbox{\hyperlink{cmsis__os_8c_aab668ffd2ea76bb0a77ab0ab385eaef2}{os\+Kernel\+Start}} (void)
\begin{DoxyCompactList}\small\item\em Start the RTOS Kernel with executing the specified thread. \end{DoxyCompactList}\item 
int32\+\_\+t \mbox{\hyperlink{cmsis__os_8c_a3b571de44cd3094c643247a7397f86b5}{os\+Kernel\+Running}} (void)
\begin{DoxyCompactList}\small\item\em Check if the RTOS kernel is already started. \end{DoxyCompactList}\item 
uint32\+\_\+t \mbox{\hyperlink{cmsis__os_8c_ad0262e4688e95d1e9038afd9bcc16001}{os\+Kernel\+Sys\+Tick}} (void)
\begin{DoxyCompactList}\small\item\em Get the value of the Kernel Sys\+Tick timer. \end{DoxyCompactList}\item 
\mbox{\hyperlink{cmsis__os_8h_a217fdd2811440d39a6e8c868a0b8ec82}{os\+Thread\+Id}} \mbox{\hyperlink{cmsis__os_8c_ac59b5713cb083702dce759c73fd90dff}{os\+Thread\+Create}} (const \mbox{\hyperlink{cmsis__os_8h_a92f46bd508dcc685135882e2cf37ac8c}{os\+Thread\+Def\+\_\+t}} \texorpdfstring{$\ast$}{*}thread\+\_\+def, void \texorpdfstring{$\ast$}{*}argument)
\begin{DoxyCompactList}\small\item\em Create a thread and add it to Active Threads and set it to state READY. \end{DoxyCompactList}\item 
\mbox{\hyperlink{cmsis__os_8h_a217fdd2811440d39a6e8c868a0b8ec82}{os\+Thread\+Id}} \mbox{\hyperlink{cmsis__os_8c_ab1df2a28925862ef8f9cf4e1c995c5a7}{os\+Thread\+Get\+Id}} (void)
\begin{DoxyCompactList}\small\item\em Return the thread ID of the current running thread. \end{DoxyCompactList}\item 
\mbox{\hyperlink{cmsis__os_8h_ae2e091fefc4c767117727bd5aba4d99e}{os\+Status}} \mbox{\hyperlink{cmsis__os_8c_aea135bb90eb853eff39e0800b91bbeab}{os\+Thread\+Terminate}} (\mbox{\hyperlink{cmsis__os_8h_a217fdd2811440d39a6e8c868a0b8ec82}{os\+Thread\+Id}} thread\+\_\+id)
\begin{DoxyCompactList}\small\item\em Terminate execution of a thread and remove it from Active Threads. \end{DoxyCompactList}\item 
\mbox{\hyperlink{cmsis__os_8h_ae2e091fefc4c767117727bd5aba4d99e}{os\+Status}} \mbox{\hyperlink{cmsis__os_8c_af13a667493c5d629a90c13e113b99233}{os\+Thread\+Yield}} (void)
\begin{DoxyCompactList}\small\item\em Pass control to next thread that is in state {\bfseries{READY}}. \end{DoxyCompactList}\item 
\mbox{\hyperlink{cmsis__os_8h_ae2e091fefc4c767117727bd5aba4d99e}{os\+Status}} \mbox{\hyperlink{cmsis__os_8c_a0dfb90ccf1f6e4b54b9251b12d1cbc8b}{os\+Thread\+Set\+Priority}} (\mbox{\hyperlink{cmsis__os_8h_a217fdd2811440d39a6e8c868a0b8ec82}{os\+Thread\+Id}} thread\+\_\+id, \mbox{\hyperlink{cmsis__os_8h_a7f2b42f1983b9107775ec2a1c69a849a}{os\+Priority}} priority)
\begin{DoxyCompactList}\small\item\em Change priority of an active thread. \end{DoxyCompactList}\item 
\mbox{\hyperlink{cmsis__os_8h_a7f2b42f1983b9107775ec2a1c69a849a}{os\+Priority}} \mbox{\hyperlink{cmsis__os_8c_a4299d838978bc2aae5e4350754e6a4e9}{os\+Thread\+Get\+Priority}} (\mbox{\hyperlink{cmsis__os_8h_a217fdd2811440d39a6e8c868a0b8ec82}{os\+Thread\+Id}} thread\+\_\+id)
\begin{DoxyCompactList}\small\item\em Get current priority of an active thread. \end{DoxyCompactList}\item 
\mbox{\hyperlink{cmsis__os_8h_ae2e091fefc4c767117727bd5aba4d99e}{os\+Status}} \mbox{\hyperlink{cmsis__os_8c_a02e19d5e723bfb06ba9324d625162255}{os\+Delay}} (uint32\+\_\+t millisec)
\begin{DoxyCompactList}\small\item\em Wait for Timeout (Time Delay) \end{DoxyCompactList}\item 
\mbox{\hyperlink{cmsis__os_8h_a6416f2f47941043a63be8453cecce5be}{os\+Timer\+Id}} \mbox{\hyperlink{cmsis__os_8c_aedd312bfdca04e0b8162b666e09a1ae6}{os\+Timer\+Create}} (const \mbox{\hyperlink{cmsis__os_8h_a2144eb7d94a485f516bf0b09078f883a}{os\+Timer\+Def\+\_\+t}} \texorpdfstring{$\ast$}{*}timer\+\_\+def, \mbox{\hyperlink{cmsis__os_8h_adac860eb9e1b4b0619271e6595ed83d9}{os\+\_\+timer\+\_\+type}} type, void \texorpdfstring{$\ast$}{*}argument)
\begin{DoxyCompactList}\small\item\em Create a timer. \end{DoxyCompactList}\item 
\mbox{\hyperlink{cmsis__os_8h_ae2e091fefc4c767117727bd5aba4d99e}{os\+Status}} \mbox{\hyperlink{cmsis__os_8c_a27a797a401b068e2644d1125f22a07ca}{os\+Timer\+Start}} (\mbox{\hyperlink{cmsis__os_8h_a6416f2f47941043a63be8453cecce5be}{os\+Timer\+Id}} timer\+\_\+id, uint32\+\_\+t millisec)
\begin{DoxyCompactList}\small\item\em Start or restart a timer. \end{DoxyCompactList}\item 
\mbox{\hyperlink{cmsis__os_8h_ae2e091fefc4c767117727bd5aba4d99e}{os\+Status}} \mbox{\hyperlink{cmsis__os_8c_a58f36b121a812936435cacc6e1e0e091}{os\+Timer\+Stop}} (\mbox{\hyperlink{cmsis__os_8h_a6416f2f47941043a63be8453cecce5be}{os\+Timer\+Id}} timer\+\_\+id)
\begin{DoxyCompactList}\small\item\em Stop a timer. \end{DoxyCompactList}\item 
\mbox{\hyperlink{cmsis__os_8h_ae2e091fefc4c767117727bd5aba4d99e}{os\+Status}} \mbox{\hyperlink{cmsis__os_8c_a746b8043d906849bd65e3900fcb483cf}{os\+Timer\+Delete}} (\mbox{\hyperlink{cmsis__os_8h_a6416f2f47941043a63be8453cecce5be}{os\+Timer\+Id}} timer\+\_\+id)
\begin{DoxyCompactList}\small\item\em Delete a timer. \end{DoxyCompactList}\item 
int32\+\_\+t \mbox{\hyperlink{cmsis__os_8c_a029340f7007656c06fdb8eeeae7b056e}{os\+Signal\+Set}} (\mbox{\hyperlink{cmsis__os_8h_a217fdd2811440d39a6e8c868a0b8ec82}{os\+Thread\+Id}} thread\+\_\+id, int32\+\_\+t signal)
\begin{DoxyCompactList}\small\item\em Set the specified Signal Flags of an active thread. \end{DoxyCompactList}\item 
int32\+\_\+t \mbox{\hyperlink{cmsis__os_8c_afcb3a9bd9a3c4c99f2f86d5d33faffd8}{os\+Signal\+Clear}} (\mbox{\hyperlink{cmsis__os_8h_a217fdd2811440d39a6e8c868a0b8ec82}{os\+Thread\+Id}} thread\+\_\+id, int32\+\_\+t signal)
\begin{DoxyCompactList}\small\item\em Clear the specified Signal Flags of an active thread. \end{DoxyCompactList}\item 
\mbox{\hyperlink{structos_event}{os\+Event}} \mbox{\hyperlink{cmsis__os_8c_a38860acda96df47da6923348d96fc4c9}{os\+Signal\+Wait}} (int32\+\_\+t signals, uint32\+\_\+t millisec)
\begin{DoxyCompactList}\small\item\em Wait for one or more Signal Flags to become signaled for the current {\bfseries{RUNNING}} thread. \end{DoxyCompactList}\item 
\mbox{\hyperlink{cmsis__os_8h_abba580e11219b5ec867b5b26ac0b87f4}{os\+Mutex\+Id}} \mbox{\hyperlink{cmsis__os_8c_a5c9de56e717016e39e788064e9a291cc}{os\+Mutex\+Create}} (const \mbox{\hyperlink{cmsis__os_8h_ac2907bdcc057de650ea61777a0e92d11}{os\+Mutex\+Def\+\_\+t}} \texorpdfstring{$\ast$}{*}mutex\+\_\+def)
\begin{DoxyCompactList}\small\item\em Create and Initialize a Mutex object. \end{DoxyCompactList}\item 
\mbox{\hyperlink{cmsis__os_8h_ae2e091fefc4c767117727bd5aba4d99e}{os\+Status}} \mbox{\hyperlink{cmsis__os_8c_a5e1752b73f573ee015dbd9ef1edaba13}{os\+Mutex\+Wait}} (\mbox{\hyperlink{cmsis__os_8h_abba580e11219b5ec867b5b26ac0b87f4}{os\+Mutex\+Id}} mutex\+\_\+id, uint32\+\_\+t millisec)
\begin{DoxyCompactList}\small\item\em Wait until a Mutex becomes available. \end{DoxyCompactList}\item 
\mbox{\hyperlink{cmsis__os_8h_ae2e091fefc4c767117727bd5aba4d99e}{os\+Status}} \mbox{\hyperlink{cmsis__os_8c_a006e4744d741e8e132c3d5bbc295afe1}{os\+Mutex\+Release}} (\mbox{\hyperlink{cmsis__os_8h_abba580e11219b5ec867b5b26ac0b87f4}{os\+Mutex\+Id}} mutex\+\_\+id)
\begin{DoxyCompactList}\small\item\em Release a Mutex that was obtained by \doxylink{cmsis__os_8c_a5e1752b73f573ee015dbd9ef1edaba13}{os\+Mutex\+Wait}. \end{DoxyCompactList}\item 
\mbox{\hyperlink{cmsis__os_8h_ae2e091fefc4c767117727bd5aba4d99e}{os\+Status}} \mbox{\hyperlink{cmsis__os_8c_ac27e24135185d51d18f3dabc20910219}{os\+Mutex\+Delete}} (\mbox{\hyperlink{cmsis__os_8h_abba580e11219b5ec867b5b26ac0b87f4}{os\+Mutex\+Id}} mutex\+\_\+id)
\begin{DoxyCompactList}\small\item\em Delete a Mutex. \end{DoxyCompactList}\item 
\mbox{\hyperlink{cmsis__os_8h_a954e9c06583b05ae736d07e4e40097d5}{os\+Semaphore\+Id}} \mbox{\hyperlink{cmsis__os_8c_a97381e8e55cd47cec390bf57c96d6edb}{os\+Semaphore\+Create}} (const \mbox{\hyperlink{cmsis__os_8h_acf4486afa668a4499003e1a750eb8ab1}{os\+Semaphore\+Def\+\_\+t}} \texorpdfstring{$\ast$}{*}semaphore\+\_\+def, int32\+\_\+t count)
\begin{DoxyCompactList}\small\item\em Create and Initialize a Semaphore object used for managing resources. \end{DoxyCompactList}\item 
int32\+\_\+t \mbox{\hyperlink{cmsis__os_8c_acc15b0fc8ce1167fe43da33042e62098}{os\+Semaphore\+Wait}} (\mbox{\hyperlink{cmsis__os_8h_a954e9c06583b05ae736d07e4e40097d5}{os\+Semaphore\+Id}} semaphore\+\_\+id, uint32\+\_\+t millisec)
\begin{DoxyCompactList}\small\item\em Wait until a Semaphore token becomes available. \end{DoxyCompactList}\item 
\mbox{\hyperlink{cmsis__os_8h_ae2e091fefc4c767117727bd5aba4d99e}{os\+Status}} \mbox{\hyperlink{cmsis__os_8c_ab108914997c49e14d8ff1ae0d1988ca0}{os\+Semaphore\+Release}} (\mbox{\hyperlink{cmsis__os_8h_a954e9c06583b05ae736d07e4e40097d5}{os\+Semaphore\+Id}} semaphore\+\_\+id)
\begin{DoxyCompactList}\small\item\em Release a Semaphore token. \end{DoxyCompactList}\item 
\mbox{\hyperlink{cmsis__os_8h_ae2e091fefc4c767117727bd5aba4d99e}{os\+Status}} \mbox{\hyperlink{cmsis__os_8c_abae2801ac2c096f6e8c69a264908f595}{os\+Semaphore\+Delete}} (\mbox{\hyperlink{cmsis__os_8h_a954e9c06583b05ae736d07e4e40097d5}{os\+Semaphore\+Id}} semaphore\+\_\+id)
\begin{DoxyCompactList}\small\item\em Delete a Semaphore. \end{DoxyCompactList}\item 
\mbox{\hyperlink{cmsis__os_8h_a08d2e20fd9bbd96220fe068d420f3686}{os\+Pool\+Id}} \mbox{\hyperlink{cmsis__os_8c_a34af5c4f4ab38f4138ea7f1f9ece3a1a}{os\+Pool\+Create}} (const \mbox{\hyperlink{cmsis__os_8h_ac47b811c41974c0bb74521a50c7983b7}{os\+Pool\+Def\+\_\+t}} \texorpdfstring{$\ast$}{*}pool\+\_\+def)
\begin{DoxyCompactList}\small\item\em Create and Initialize a memory pool. \end{DoxyCompactList}\item 
void \texorpdfstring{$\ast$}{*} \mbox{\hyperlink{cmsis__os_8c_aa0b2994f1a866c19e0d11e6e0d44f543}{os\+Pool\+Alloc}} (\mbox{\hyperlink{cmsis__os_8h_a08d2e20fd9bbd96220fe068d420f3686}{os\+Pool\+Id}} pool\+\_\+id)
\begin{DoxyCompactList}\small\item\em Allocate a memory block from a memory pool. \end{DoxyCompactList}\item 
void \texorpdfstring{$\ast$}{*} \mbox{\hyperlink{cmsis__os_8c_a9f129fcad4730fbd1048ad4fa262f36a}{os\+Pool\+CAlloc}} (\mbox{\hyperlink{cmsis__os_8h_a08d2e20fd9bbd96220fe068d420f3686}{os\+Pool\+Id}} pool\+\_\+id)
\begin{DoxyCompactList}\small\item\em Allocate a memory block from a memory pool and set memory block to zero. \end{DoxyCompactList}\item 
\mbox{\hyperlink{cmsis__os_8h_ae2e091fefc4c767117727bd5aba4d99e}{os\+Status}} \mbox{\hyperlink{cmsis__os_8c_a4a861e9c469c9d0daf5721bf174f8e54}{os\+Pool\+Free}} (\mbox{\hyperlink{cmsis__os_8h_a08d2e20fd9bbd96220fe068d420f3686}{os\+Pool\+Id}} pool\+\_\+id, void \texorpdfstring{$\ast$}{*}block)
\begin{DoxyCompactList}\small\item\em Return an allocated memory block back to a specific memory pool. \end{DoxyCompactList}\item 
\mbox{\hyperlink{cmsis__os_8h_a8c191fd2b1369c8942873496a186a022}{os\+Message\+QId}} \mbox{\hyperlink{cmsis__os_8c_af3b9345cf426304d46565152bc26fb78}{os\+Message\+Create}} (const \mbox{\hyperlink{cmsis__os_8h_a552ffc97e37e403acff6a59793ad26eb}{os\+Message\+QDef\+\_\+t}} \texorpdfstring{$\ast$}{*}queue\+\_\+def, \mbox{\hyperlink{cmsis__os_8h_a217fdd2811440d39a6e8c868a0b8ec82}{os\+Thread\+Id}} thread\+\_\+id)
\begin{DoxyCompactList}\small\item\em Create and Initialize a Message Queue. \end{DoxyCompactList}\item 
\mbox{\hyperlink{cmsis__os_8h_ae2e091fefc4c767117727bd5aba4d99e}{os\+Status}} \mbox{\hyperlink{cmsis__os_8c_ac0dcf462fc92de8ffaba6cc004514a6d}{os\+Message\+Put}} (\mbox{\hyperlink{cmsis__os_8h_a8c191fd2b1369c8942873496a186a022}{os\+Message\+QId}} queue\+\_\+id, uint32\+\_\+t info, uint32\+\_\+t millisec)
\begin{DoxyCompactList}\small\item\em Put a Message to a Queue. \end{DoxyCompactList}\item 
\mbox{\hyperlink{structos_event}{os\+Event}} \mbox{\hyperlink{cmsis__os_8c_a6c6892b8f2296cca6becd57ca2d7e1ae}{os\+Message\+Get}} (\mbox{\hyperlink{cmsis__os_8h_a8c191fd2b1369c8942873496a186a022}{os\+Message\+QId}} queue\+\_\+id, uint32\+\_\+t millisec)
\begin{DoxyCompactList}\small\item\em Get a Message or Wait for a Message from a Queue. \end{DoxyCompactList}\item 
\mbox{\hyperlink{cmsis__os_8h_a1dac049fb7725a8af8b26c71cbb373b5}{os\+Mail\+QId}} \mbox{\hyperlink{cmsis__os_8c_aa177e7fe5820dd70d8c9e46ded131174}{os\+Mail\+Create}} (const \mbox{\hyperlink{cmsis__os_8h_ab6d3ddc7d8cea9901544118bed1a3d1c}{os\+Mail\+QDef\+\_\+t}} \texorpdfstring{$\ast$}{*}queue\+\_\+def, \mbox{\hyperlink{cmsis__os_8h_a217fdd2811440d39a6e8c868a0b8ec82}{os\+Thread\+Id}} thread\+\_\+id)
\begin{DoxyCompactList}\small\item\em Create and Initialize mail queue. \end{DoxyCompactList}\item 
void \texorpdfstring{$\ast$}{*} \mbox{\hyperlink{cmsis__os_8c_adf5ce811bd6a56e617e902a1db6c2194}{os\+Mail\+Alloc}} (\mbox{\hyperlink{cmsis__os_8h_a1dac049fb7725a8af8b26c71cbb373b5}{os\+Mail\+QId}} queue\+\_\+id, uint32\+\_\+t millisec)
\begin{DoxyCompactList}\small\item\em Allocate a memory block from a mail. \end{DoxyCompactList}\item 
void \texorpdfstring{$\ast$}{*} \mbox{\hyperlink{cmsis__os_8c_a8fde74f6fe5b9e88f75cc5eb8f2124fd}{os\+Mail\+CAlloc}} (\mbox{\hyperlink{cmsis__os_8h_a1dac049fb7725a8af8b26c71cbb373b5}{os\+Mail\+QId}} queue\+\_\+id, uint32\+\_\+t millisec)
\begin{DoxyCompactList}\small\item\em Allocate a memory block from a mail and set memory block to zero. \end{DoxyCompactList}\item 
\mbox{\hyperlink{cmsis__os_8h_ae2e091fefc4c767117727bd5aba4d99e}{os\+Status}} \mbox{\hyperlink{cmsis__os_8c_a485ef6f81854ebda8ffbce4832181e02}{os\+Mail\+Put}} (\mbox{\hyperlink{cmsis__os_8h_a1dac049fb7725a8af8b26c71cbb373b5}{os\+Mail\+QId}} queue\+\_\+id, void \texorpdfstring{$\ast$}{*}mail)
\begin{DoxyCompactList}\small\item\em Put a mail to a queue. \end{DoxyCompactList}\item 
\mbox{\hyperlink{structos_event}{os\+Event}} \mbox{\hyperlink{cmsis__os_8c_ac6ad7e6e7d6c4a80e60da22c57a42ccd}{os\+Mail\+Get}} (\mbox{\hyperlink{cmsis__os_8h_a1dac049fb7725a8af8b26c71cbb373b5}{os\+Mail\+QId}} queue\+\_\+id, uint32\+\_\+t millisec)
\begin{DoxyCompactList}\small\item\em Get a mail from a queue. \end{DoxyCompactList}\item 
\mbox{\hyperlink{cmsis__os_8h_ae2e091fefc4c767117727bd5aba4d99e}{os\+Status}} \mbox{\hyperlink{cmsis__os_8c_a27c1060cf21393f96b4fd1ed1c0167cc}{os\+Mail\+Free}} (\mbox{\hyperlink{cmsis__os_8h_a1dac049fb7725a8af8b26c71cbb373b5}{os\+Mail\+QId}} queue\+\_\+id, void \texorpdfstring{$\ast$}{*}mail)
\begin{DoxyCompactList}\small\item\em Free a memory block from a mail. \end{DoxyCompactList}\item 
void \mbox{\hyperlink{cmsis__os_8c_ab169d629ebefc57e030b324d4cce9eea}{os\+Systick\+Handler}} (void)
\begin{DoxyCompactList}\small\item\em Handles the tick increment. \end{DoxyCompactList}\item 
\mbox{\hyperlink{cmsis__os_8h_ae2e091fefc4c767117727bd5aba4d99e}{os\+Status}} \mbox{\hyperlink{cmsis__os_8c_a204bf99a22ca8fe85b1f8028f0268278}{os\+Thread\+Suspend}} (\mbox{\hyperlink{cmsis__os_8h_a217fdd2811440d39a6e8c868a0b8ec82}{os\+Thread\+Id}} thread\+\_\+id)
\begin{DoxyCompactList}\small\item\em Suspend execution of a thread. \end{DoxyCompactList}\item 
\mbox{\hyperlink{cmsis__os_8h_ae2e091fefc4c767117727bd5aba4d99e}{os\+Status}} \mbox{\hyperlink{cmsis__os_8c_a98905f234a096669566e7b93272b2653}{os\+Thread\+Resume}} (\mbox{\hyperlink{cmsis__os_8h_a217fdd2811440d39a6e8c868a0b8ec82}{os\+Thread\+Id}} thread\+\_\+id)
\begin{DoxyCompactList}\small\item\em Resume execution of a suspended thread. \end{DoxyCompactList}\item 
\mbox{\hyperlink{cmsis__os_8h_ae2e091fefc4c767117727bd5aba4d99e}{os\+Status}} \mbox{\hyperlink{cmsis__os_8c_a56a2ad8a2fb63a7fdad28d2e9411c3a1}{os\+Thread\+Suspend\+All}} (void)
\begin{DoxyCompactList}\small\item\em Suspend execution of a all active threads. \end{DoxyCompactList}\item 
\mbox{\hyperlink{cmsis__os_8h_ae2e091fefc4c767117727bd5aba4d99e}{os\+Status}} \mbox{\hyperlink{cmsis__os_8c_a909a8098efc243cec5729ac51fdb3bdc}{os\+Thread\+Resume\+All}} (void)
\begin{DoxyCompactList}\small\item\em Resume execution of a all suspended threads. \end{DoxyCompactList}\item 
\mbox{\hyperlink{cmsis__os_8h_ae2e091fefc4c767117727bd5aba4d99e}{os\+Status}} \mbox{\hyperlink{cmsis__os_8c_afc406147a5d66dda6ff62d338a7c99cd}{os\+Delay\+Until}} (uint32\+\_\+t \texorpdfstring{$\ast$}{*}Previous\+Wake\+Time, uint32\+\_\+t millisec)
\begin{DoxyCompactList}\small\item\em Delay a task until a specified time. \end{DoxyCompactList}\item 
\mbox{\hyperlink{cmsis__os_8h_ae2e091fefc4c767117727bd5aba4d99e}{os\+Status}} \mbox{\hyperlink{cmsis__os_8c_a0c9e0cca7aca466bb8887fb56e4b4cc8}{os\+Abort\+Delay}} (\mbox{\hyperlink{cmsis__os_8h_a217fdd2811440d39a6e8c868a0b8ec82}{os\+Thread\+Id}} thread\+\_\+id)
\begin{DoxyCompactList}\small\item\em Abort the delay for a specific thread. \end{DoxyCompactList}\item 
\mbox{\hyperlink{cmsis__os_8h_ae2e091fefc4c767117727bd5aba4d99e}{os\+Status}} \mbox{\hyperlink{cmsis__os_8c_a72dea6af29c3caa97b583da895237697}{os\+Thread\+List}} (uint8\+\_\+t \texorpdfstring{$\ast$}{*}buffer)
\begin{DoxyCompactList}\small\item\em Lists all the current threads, along with their current state and stack usage high water mark. \end{DoxyCompactList}\item 
\mbox{\hyperlink{structos_event}{os\+Event}} \mbox{\hyperlink{cmsis__os_8c_aee1081c573fe04809315378a37c0ce23}{os\+Message\+Peek}} (\mbox{\hyperlink{cmsis__os_8h_a8c191fd2b1369c8942873496a186a022}{os\+Message\+QId}} queue\+\_\+id, uint32\+\_\+t millisec)
\begin{DoxyCompactList}\small\item\em Receive an item from a queue without removing the item from the queue. \end{DoxyCompactList}\item 
uint32\+\_\+t \mbox{\hyperlink{cmsis__os_8c_a272501325655aa8bbf36ecd36e38bc56}{os\+Message\+Waiting}} (\mbox{\hyperlink{cmsis__os_8h_a8c191fd2b1369c8942873496a186a022}{os\+Message\+QId}} queue\+\_\+id)
\begin{DoxyCompactList}\small\item\em Get the number of messaged stored in a queue. \end{DoxyCompactList}\item 
uint32\+\_\+t \mbox{\hyperlink{cmsis__os_8c_a4f80ea3dd0140a782dc3e79fc7d1cba6}{os\+Message\+Available\+Space}} (\mbox{\hyperlink{cmsis__os_8h_a8c191fd2b1369c8942873496a186a022}{os\+Message\+QId}} queue\+\_\+id)
\begin{DoxyCompactList}\small\item\em Get the available space in a message queue. \end{DoxyCompactList}\item 
\mbox{\hyperlink{cmsis__os_8h_ae2e091fefc4c767117727bd5aba4d99e}{os\+Status}} \mbox{\hyperlink{cmsis__os_8c_aa6eff4b4ee9e73ab881840eaf329c469}{os\+Message\+Delete}} (\mbox{\hyperlink{cmsis__os_8h_a8c191fd2b1369c8942873496a186a022}{os\+Message\+QId}} queue\+\_\+id)
\begin{DoxyCompactList}\small\item\em Delete a Message Queue. \end{DoxyCompactList}\item 
\mbox{\hyperlink{cmsis__os_8h_abba580e11219b5ec867b5b26ac0b87f4}{os\+Mutex\+Id}} \mbox{\hyperlink{cmsis__os_8c_a09a8e658872a88d284f8143bcb62cff6}{os\+Recursive\+Mutex\+Create}} (const \mbox{\hyperlink{cmsis__os_8h_ac2907bdcc057de650ea61777a0e92d11}{os\+Mutex\+Def\+\_\+t}} \texorpdfstring{$\ast$}{*}mutex\+\_\+def)
\begin{DoxyCompactList}\small\item\em Create and Initialize a Recursive Mutex. \end{DoxyCompactList}\item 
\mbox{\hyperlink{cmsis__os_8h_ae2e091fefc4c767117727bd5aba4d99e}{os\+Status}} \mbox{\hyperlink{cmsis__os_8c_a14c641c81a487a21851555cab5c04531}{os\+Recursive\+Mutex\+Release}} (\mbox{\hyperlink{cmsis__os_8h_abba580e11219b5ec867b5b26ac0b87f4}{os\+Mutex\+Id}} mutex\+\_\+id)
\begin{DoxyCompactList}\small\item\em Release a Recursive Mutex. \end{DoxyCompactList}\item 
\mbox{\hyperlink{cmsis__os_8h_ae2e091fefc4c767117727bd5aba4d99e}{os\+Status}} \mbox{\hyperlink{cmsis__os_8c_a479c5c0d01b4f43854761026d2054b30}{os\+Recursive\+Mutex\+Wait}} (\mbox{\hyperlink{cmsis__os_8h_abba580e11219b5ec867b5b26ac0b87f4}{os\+Mutex\+Id}} mutex\+\_\+id, uint32\+\_\+t millisec)
\begin{DoxyCompactList}\small\item\em Release a Recursive Mutex. \end{DoxyCompactList}\item 
uint32\+\_\+t \mbox{\hyperlink{cmsis__os_8c_a5aaec061a877326be39a4998f7690567}{os\+Semaphore\+Get\+Count}} (\mbox{\hyperlink{cmsis__os_8h_a954e9c06583b05ae736d07e4e40097d5}{os\+Semaphore\+Id}} semaphore\+\_\+id)
\begin{DoxyCompactList}\small\item\em Returns the current count value of a counting semaphore. \end{DoxyCompactList}\end{DoxyCompactItemize}

\doxysubsection{Documentation des définitions de type}
\Hypertarget{cmsis__os_8c_a5afb33e919c9d492d5033933b33179d7}\index{cmsis\_os.c@{cmsis\_os.c}!os\_mailQ\_cb\_t@{os\_mailQ\_cb\_t}}
\index{os\_mailQ\_cb\_t@{os\_mailQ\_cb\_t}!cmsis\_os.c@{cmsis\_os.c}}
\doxysubsubsection{\texorpdfstring{os\_mailQ\_cb\_t}{os\_mailQ\_cb\_t}}
{\footnotesize\ttfamily \label{cmsis__os_8c_a5afb33e919c9d492d5033933b33179d7} 
typedef struct \mbox{\hyperlink{structos__mail_q__cb}{os\+\_\+mail\+Q\+\_\+cb}} \mbox{\hyperlink{cmsis__os_8c_a5afb33e919c9d492d5033933b33179d7}{os\+\_\+mail\+Q\+\_\+cb\+\_\+t}}}

\Hypertarget{cmsis__os_8c_a5843b92c9bd46a1c4f0de680a56537f4}\index{cmsis\_os.c@{cmsis\_os.c}!os\_pool\_cb\_t@{os\_pool\_cb\_t}}
\index{os\_pool\_cb\_t@{os\_pool\_cb\_t}!cmsis\_os.c@{cmsis\_os.c}}
\doxysubsubsection{\texorpdfstring{os\_pool\_cb\_t}{os\_pool\_cb\_t}}
{\footnotesize\ttfamily \label{cmsis__os_8c_a5843b92c9bd46a1c4f0de680a56537f4} 
typedef struct \mbox{\hyperlink{structos__pool__cb}{os\+\_\+pool\+\_\+cb}} \mbox{\hyperlink{cmsis__os_8c_a5843b92c9bd46a1c4f0de680a56537f4}{os\+\_\+pool\+\_\+cb\+\_\+t}}}

\doxysubsection{Documentation des fonctions}
\Hypertarget{cmsis__os_8c_a0c9e0cca7aca466bb8887fb56e4b4cc8}\index{cmsis\_os.c@{cmsis\_os.c}!osAbortDelay@{osAbortDelay}}
\index{osAbortDelay@{osAbortDelay}!cmsis\_os.c@{cmsis\_os.c}}
\doxysubsubsection{\texorpdfstring{osAbortDelay()}{osAbortDelay()}}
{\footnotesize\ttfamily \label{cmsis__os_8c_a0c9e0cca7aca466bb8887fb56e4b4cc8} 
\mbox{\hyperlink{cmsis__os_8h_ae2e091fefc4c767117727bd5aba4d99e}{os\+Status}} os\+Abort\+Delay (\begin{DoxyParamCaption}\item[{\mbox{\hyperlink{cmsis__os_8h_a217fdd2811440d39a6e8c868a0b8ec82}{os\+Thread\+Id}}}]{thread\+\_\+id}{}\end{DoxyParamCaption})}

Abort the delay for a specific thread. 

\begin{DoxyParams}{Paramètres}
{\em thread\+\_\+id} & thread ID obtained by \doxylink{cmsis__os_8c_ac59b5713cb083702dce759c73fd90dff}{os\+Thread\+Create} or \doxylink{cmsis__os_8c_ab1df2a28925862ef8f9cf4e1c995c5a7}{os\+Thread\+Get\+Id} ~\newline
 \\
\hline
\end{DoxyParams}

\begin{DoxyRetVals}{Valeurs retournées}
{\em status} & code that indicates the execution status of the function. \\
\hline
\end{DoxyRetVals}
\Hypertarget{cmsis__os_8c_a02e19d5e723bfb06ba9324d625162255}\index{cmsis\_os.c@{cmsis\_os.c}!osDelay@{osDelay}}
\index{osDelay@{osDelay}!cmsis\_os.c@{cmsis\_os.c}}
\doxysubsubsection{\texorpdfstring{osDelay()}{osDelay()}}
{\footnotesize\ttfamily \label{cmsis__os_8c_a02e19d5e723bfb06ba9324d625162255} 
\mbox{\hyperlink{cmsis__os_8h_ae2e091fefc4c767117727bd5aba4d99e}{os\+Status}} os\+Delay (\begin{DoxyParamCaption}\item[{uint32\+\_\+t}]{millisec}{}\end{DoxyParamCaption})}

Wait for Timeout (Time Delay) 

\begin{DoxyParams}{Paramètres}
{\em millisec} & time delay value \\
\hline
\end{DoxyParams}

\begin{DoxyRetVals}{Valeurs retournées}
{\em status} & code that indicates the execution status of the function. \\
\hline
\end{DoxyRetVals}
\Hypertarget{cmsis__os_8c_afc406147a5d66dda6ff62d338a7c99cd}\index{cmsis\_os.c@{cmsis\_os.c}!osDelayUntil@{osDelayUntil}}
\index{osDelayUntil@{osDelayUntil}!cmsis\_os.c@{cmsis\_os.c}}
\doxysubsubsection{\texorpdfstring{osDelayUntil()}{osDelayUntil()}}
{\footnotesize\ttfamily \label{cmsis__os_8c_afc406147a5d66dda6ff62d338a7c99cd} 
\mbox{\hyperlink{cmsis__os_8h_ae2e091fefc4c767117727bd5aba4d99e}{os\+Status}} os\+Delay\+Until (\begin{DoxyParamCaption}\item[{uint32\+\_\+t \texorpdfstring{$\ast$}{*}}]{Previous\+Wake\+Time}{, }\item[{uint32\+\_\+t}]{millisec}{}\end{DoxyParamCaption})}

Delay a task until a specified time. 

\begin{DoxyParams}{Paramètres}
{\em Previous\+Wake\+Time} & Pointer to a variable that holds the time at which the task was last unblocked. Previous\+Wake\+Time must be initialised with the current time prior to its first use (Previous\+Wake\+Time = \doxylink{cmsis__os_8c_ad0262e4688e95d1e9038afd9bcc16001}{os\+Kernel\+Sys\+Tick()} ) \\
\hline
{\em millisec} & time delay value \\
\hline
\end{DoxyParams}

\begin{DoxyRetVals}{Valeurs retournées}
{\em status} & code that indicates the execution status of the function. \\
\hline
\end{DoxyRetVals}
\Hypertarget{cmsis__os_8c_a53d078a801022e202e8115c083ece68e}\index{cmsis\_os.c@{cmsis\_os.c}!osKernelInitialize@{osKernelInitialize}}
\index{osKernelInitialize@{osKernelInitialize}!cmsis\_os.c@{cmsis\_os.c}}
\doxysubsubsection{\texorpdfstring{osKernelInitialize()}{osKernelInitialize()}}
{\footnotesize\ttfamily \label{cmsis__os_8c_a53d078a801022e202e8115c083ece68e} 
\mbox{\hyperlink{cmsis__os_8h_ae2e091fefc4c767117727bd5aba4d99e}{os\+Status}} os\+Kernel\+Initialize (\begin{DoxyParamCaption}\item[{void}]{}{}\end{DoxyParamCaption})}

Initialize the RTOS Kernel for creating objects. 

\begin{DoxyRetVals}{Valeurs retournées}
{\em status} & code that indicates the execution status of the function. \\
\hline
\end{DoxyRetVals}
\begin{DoxyNote}{Note}
MUST REMAIN UNCHANGED\+: {\bfseries{os\+Kernel\+Initialize}} shall be consistent in every CMSIS-\/\+RTOS. 
\end{DoxyNote}
\Hypertarget{cmsis__os_8c_a3b571de44cd3094c643247a7397f86b5}\index{cmsis\_os.c@{cmsis\_os.c}!osKernelRunning@{osKernelRunning}}
\index{osKernelRunning@{osKernelRunning}!cmsis\_os.c@{cmsis\_os.c}}
\doxysubsubsection{\texorpdfstring{osKernelRunning()}{osKernelRunning()}}
{\footnotesize\ttfamily \label{cmsis__os_8c_a3b571de44cd3094c643247a7397f86b5} 
int32\+\_\+t os\+Kernel\+Running (\begin{DoxyParamCaption}\item[{void}]{}{}\end{DoxyParamCaption})}

Check if the RTOS kernel is already started. 

\begin{DoxyParams}{Paramètres}
{\em None} & \\
\hline
\end{DoxyParams}

\begin{DoxyRetVals}{Valeurs retournées}
{\em (0)} & RTOS is not started (1) RTOS is started (-\/1) if this feature is disabled in \doxylink{_free_r_t_o_s_config_8h}{Free\+RTOSConfig.\+h} \\
\hline
\end{DoxyRetVals}
\begin{DoxyNote}{Note}
MUST REMAIN UNCHANGED\+: {\bfseries{os\+Kernel\+Running}} shall be consistent in every CMSIS-\/\+RTOS. 
\end{DoxyNote}
\Hypertarget{cmsis__os_8c_aab668ffd2ea76bb0a77ab0ab385eaef2}\index{cmsis\_os.c@{cmsis\_os.c}!osKernelStart@{osKernelStart}}
\index{osKernelStart@{osKernelStart}!cmsis\_os.c@{cmsis\_os.c}}
\doxysubsubsection{\texorpdfstring{osKernelStart()}{osKernelStart()}}
{\footnotesize\ttfamily \label{cmsis__os_8c_aab668ffd2ea76bb0a77ab0ab385eaef2} 
\mbox{\hyperlink{cmsis__os_8h_ae2e091fefc4c767117727bd5aba4d99e}{os\+Status}} os\+Kernel\+Start (\begin{DoxyParamCaption}\item[{void}]{}{}\end{DoxyParamCaption})}

Start the RTOS Kernel with executing the specified thread. 

\begin{DoxyParams}{Paramètres}
{\em thread\+\_\+def} & thread definition referenced with \doxylink{cmsis__os_8h_af0c7c6b5e09f8be198312144b5c9e453}{os\+Thread}. \\
\hline
{\em argument} & pointer that is passed to the thread function as start argument. \\
\hline
\end{DoxyParams}

\begin{DoxyRetVals}{Valeurs retournées}
{\em status} & code that indicates the execution status of the function \\
\hline
\end{DoxyRetVals}
\begin{DoxyNote}{Note}
MUST REMAIN UNCHANGED\+: {\bfseries{os\+Kernel\+Start}} shall be consistent in every CMSIS-\/\+RTOS. 
\end{DoxyNote}
\Hypertarget{cmsis__os_8c_ad0262e4688e95d1e9038afd9bcc16001}\index{cmsis\_os.c@{cmsis\_os.c}!osKernelSysTick@{osKernelSysTick}}
\index{osKernelSysTick@{osKernelSysTick}!cmsis\_os.c@{cmsis\_os.c}}
\doxysubsubsection{\texorpdfstring{osKernelSysTick()}{osKernelSysTick()}}
{\footnotesize\ttfamily \label{cmsis__os_8c_ad0262e4688e95d1e9038afd9bcc16001} 
uint32\+\_\+t os\+Kernel\+Sys\+Tick (\begin{DoxyParamCaption}\item[{void}]{}{}\end{DoxyParamCaption})}

Get the value of the Kernel Sys\+Tick timer. 

\begin{DoxyParams}{Paramètres}
{\em None} & \\
\hline
\end{DoxyParams}

\begin{DoxyRetVals}{Valeurs retournées}
{\em None} & \\
\hline
\end{DoxyRetVals}
\begin{DoxyNote}{Note}
MUST REMAIN UNCHANGED\+: {\bfseries{os\+Kernel\+Sys\+Tick}} shall be consistent in every CMSIS-\/\+RTOS. 
\end{DoxyNote}
\Hypertarget{cmsis__os_8c_adf5ce811bd6a56e617e902a1db6c2194}\index{cmsis\_os.c@{cmsis\_os.c}!osMailAlloc@{osMailAlloc}}
\index{osMailAlloc@{osMailAlloc}!cmsis\_os.c@{cmsis\_os.c}}
\doxysubsubsection{\texorpdfstring{osMailAlloc()}{osMailAlloc()}}
{\footnotesize\ttfamily \label{cmsis__os_8c_adf5ce811bd6a56e617e902a1db6c2194} 
void \texorpdfstring{$\ast$}{*} os\+Mail\+Alloc (\begin{DoxyParamCaption}\item[{\mbox{\hyperlink{cmsis__os_8h_a1dac049fb7725a8af8b26c71cbb373b5}{os\+Mail\+QId}}}]{queue\+\_\+id}{, }\item[{uint32\+\_\+t}]{millisec}{}\end{DoxyParamCaption})}

Allocate a memory block from a mail. 

\begin{DoxyParams}{Paramètres}
{\em queue\+\_\+id} & mail queue ID obtained with \doxylink{cmsis__os_8c_aa177e7fe5820dd70d8c9e46ded131174}{os\+Mail\+Create}. \\
\hline
{\em millisec} & timeout value or 0 in case of no time-\/out. \\
\hline
\end{DoxyParams}

\begin{DoxyRetVals}{Valeurs retournées}
{\em pointer} & to memory block that can be filled with mail or NULL in case error. \\
\hline
\end{DoxyRetVals}
\begin{DoxyNote}{Note}
MUST REMAIN UNCHANGED\+: {\bfseries{os\+Mail\+Alloc}} shall be consistent in every CMSIS-\/\+RTOS. 
\end{DoxyNote}
\Hypertarget{cmsis__os_8c_a8fde74f6fe5b9e88f75cc5eb8f2124fd}\index{cmsis\_os.c@{cmsis\_os.c}!osMailCAlloc@{osMailCAlloc}}
\index{osMailCAlloc@{osMailCAlloc}!cmsis\_os.c@{cmsis\_os.c}}
\doxysubsubsection{\texorpdfstring{osMailCAlloc()}{osMailCAlloc()}}
{\footnotesize\ttfamily \label{cmsis__os_8c_a8fde74f6fe5b9e88f75cc5eb8f2124fd} 
void \texorpdfstring{$\ast$}{*} os\+Mail\+CAlloc (\begin{DoxyParamCaption}\item[{\mbox{\hyperlink{cmsis__os_8h_a1dac049fb7725a8af8b26c71cbb373b5}{os\+Mail\+QId}}}]{queue\+\_\+id}{, }\item[{uint32\+\_\+t}]{millisec}{}\end{DoxyParamCaption})}

Allocate a memory block from a mail and set memory block to zero. 

\begin{DoxyParams}{Paramètres}
{\em queue\+\_\+id} & mail queue ID obtained with \doxylink{cmsis__os_8c_aa177e7fe5820dd70d8c9e46ded131174}{os\+Mail\+Create}. \\
\hline
{\em millisec} & timeout value or 0 in case of no time-\/out. \\
\hline
\end{DoxyParams}

\begin{DoxyRetVals}{Valeurs retournées}
{\em pointer} & to memory block that can be filled with mail or NULL in case error. \\
\hline
\end{DoxyRetVals}
\begin{DoxyNote}{Note}
MUST REMAIN UNCHANGED\+: {\bfseries{os\+Mail\+CAlloc}} shall be consistent in every CMSIS-\/\+RTOS. 
\end{DoxyNote}
\Hypertarget{cmsis__os_8c_aa177e7fe5820dd70d8c9e46ded131174}\index{cmsis\_os.c@{cmsis\_os.c}!osMailCreate@{osMailCreate}}
\index{osMailCreate@{osMailCreate}!cmsis\_os.c@{cmsis\_os.c}}
\doxysubsubsection{\texorpdfstring{osMailCreate()}{osMailCreate()}}
{\footnotesize\ttfamily \label{cmsis__os_8c_aa177e7fe5820dd70d8c9e46ded131174} 
\mbox{\hyperlink{cmsis__os_8h_a1dac049fb7725a8af8b26c71cbb373b5}{os\+Mail\+QId}} os\+Mail\+Create (\begin{DoxyParamCaption}\item[{const \mbox{\hyperlink{cmsis__os_8h_ab6d3ddc7d8cea9901544118bed1a3d1c}{os\+Mail\+QDef\+\_\+t}} \texorpdfstring{$\ast$}{*}}]{queue\+\_\+def}{, }\item[{\mbox{\hyperlink{cmsis__os_8h_a217fdd2811440d39a6e8c868a0b8ec82}{os\+Thread\+Id}}}]{thread\+\_\+id}{}\end{DoxyParamCaption})}

Create and Initialize mail queue. 

\begin{DoxyParams}{Paramètres}
{\em queue\+\_\+def} & reference to the mail queue definition obtain with \doxylink{cmsis__os_8h_ad2deeb66d51ade54e63d8f87ff2ec9d2}{os\+MailQ} \\
\hline
{\em thread\+\_\+id} & thread ID (obtained by \doxylink{cmsis__os_8c_ac59b5713cb083702dce759c73fd90dff}{os\+Thread\+Create} or \doxylink{cmsis__os_8c_ab1df2a28925862ef8f9cf4e1c995c5a7}{os\+Thread\+Get\+Id}) or NULL. \\
\hline
\end{DoxyParams}

\begin{DoxyRetVals}{Valeurs retournées}
{\em mail} & queue ID for reference by other functions or NULL in case of error. \\
\hline
\end{DoxyRetVals}
\begin{DoxyNote}{Note}
MUST REMAIN UNCHANGED\+: {\bfseries{os\+Mail\+Create}} shall be consistent in every CMSIS-\/\+RTOS. 
\end{DoxyNote}
\Hypertarget{cmsis__os_8c_a27c1060cf21393f96b4fd1ed1c0167cc}\index{cmsis\_os.c@{cmsis\_os.c}!osMailFree@{osMailFree}}
\index{osMailFree@{osMailFree}!cmsis\_os.c@{cmsis\_os.c}}
\doxysubsubsection{\texorpdfstring{osMailFree()}{osMailFree()}}
{\footnotesize\ttfamily \label{cmsis__os_8c_a27c1060cf21393f96b4fd1ed1c0167cc} 
\mbox{\hyperlink{cmsis__os_8h_ae2e091fefc4c767117727bd5aba4d99e}{os\+Status}} os\+Mail\+Free (\begin{DoxyParamCaption}\item[{\mbox{\hyperlink{cmsis__os_8h_a1dac049fb7725a8af8b26c71cbb373b5}{os\+Mail\+QId}}}]{queue\+\_\+id}{, }\item[{void \texorpdfstring{$\ast$}{*}}]{mail}{}\end{DoxyParamCaption})}

Free a memory block from a mail. 

\begin{DoxyParams}{Paramètres}
{\em queue\+\_\+id} & mail queue ID obtained with \doxylink{cmsis__os_8c_aa177e7fe5820dd70d8c9e46ded131174}{os\+Mail\+Create}. \\
\hline
{\em mail} & pointer to the memory block that was obtained with \doxylink{cmsis__os_8c_ac6ad7e6e7d6c4a80e60da22c57a42ccd}{os\+Mail\+Get}. \\
\hline
\end{DoxyParams}

\begin{DoxyRetVals}{Valeurs retournées}
{\em status} & code that indicates the execution status of the function. \\
\hline
\end{DoxyRetVals}
\begin{DoxyNote}{Note}
MUST REMAIN UNCHANGED\+: {\bfseries{os\+Mail\+Free}} shall be consistent in every CMSIS-\/\+RTOS. 
\end{DoxyNote}
\Hypertarget{cmsis__os_8c_ac6ad7e6e7d6c4a80e60da22c57a42ccd}\index{cmsis\_os.c@{cmsis\_os.c}!osMailGet@{osMailGet}}
\index{osMailGet@{osMailGet}!cmsis\_os.c@{cmsis\_os.c}}
\doxysubsubsection{\texorpdfstring{osMailGet()}{osMailGet()}}
{\footnotesize\ttfamily \label{cmsis__os_8c_ac6ad7e6e7d6c4a80e60da22c57a42ccd} 
\mbox{\hyperlink{structos_event}{os\+Event}} os\+Mail\+Get (\begin{DoxyParamCaption}\item[{\mbox{\hyperlink{cmsis__os_8h_a1dac049fb7725a8af8b26c71cbb373b5}{os\+Mail\+QId}}}]{queue\+\_\+id}{, }\item[{uint32\+\_\+t}]{millisec}{}\end{DoxyParamCaption})}

Get a mail from a queue. 

\begin{DoxyParams}{Paramètres}
{\em queue\+\_\+id} & mail queue ID obtained with \doxylink{cmsis__os_8c_aa177e7fe5820dd70d8c9e46ded131174}{os\+Mail\+Create}. \\
\hline
{\em millisec} & timeout value or 0 in case of no time-\/out \\
\hline
\end{DoxyParams}

\begin{DoxyRetVals}{Valeurs retournées}
{\em event} & that contains mail information or error code. \\
\hline
\end{DoxyRetVals}
\begin{DoxyNote}{Note}
MUST REMAIN UNCHANGED\+: {\bfseries{os\+Mail\+Get}} shall be consistent in every CMSIS-\/\+RTOS. 
\end{DoxyNote}
\Hypertarget{cmsis__os_8c_a485ef6f81854ebda8ffbce4832181e02}\index{cmsis\_os.c@{cmsis\_os.c}!osMailPut@{osMailPut}}
\index{osMailPut@{osMailPut}!cmsis\_os.c@{cmsis\_os.c}}
\doxysubsubsection{\texorpdfstring{osMailPut()}{osMailPut()}}
{\footnotesize\ttfamily \label{cmsis__os_8c_a485ef6f81854ebda8ffbce4832181e02} 
\mbox{\hyperlink{cmsis__os_8h_ae2e091fefc4c767117727bd5aba4d99e}{os\+Status}} os\+Mail\+Put (\begin{DoxyParamCaption}\item[{\mbox{\hyperlink{cmsis__os_8h_a1dac049fb7725a8af8b26c71cbb373b5}{os\+Mail\+QId}}}]{queue\+\_\+id}{, }\item[{void \texorpdfstring{$\ast$}{*}}]{mail}{}\end{DoxyParamCaption})}

Put a mail to a queue. 

\begin{DoxyParams}{Paramètres}
{\em queue\+\_\+id} & mail queue ID obtained with \doxylink{cmsis__os_8c_aa177e7fe5820dd70d8c9e46ded131174}{os\+Mail\+Create}. \\
\hline
{\em mail} & memory block previously allocated with \doxylink{cmsis__os_8c_adf5ce811bd6a56e617e902a1db6c2194}{os\+Mail\+Alloc} or \doxylink{cmsis__os_8c_a8fde74f6fe5b9e88f75cc5eb8f2124fd}{os\+Mail\+CAlloc}. \\
\hline
\end{DoxyParams}

\begin{DoxyRetVals}{Valeurs retournées}
{\em status} & code that indicates the execution status of the function. \\
\hline
\end{DoxyRetVals}
\begin{DoxyNote}{Note}
MUST REMAIN UNCHANGED\+: {\bfseries{os\+Mail\+Put}} shall be consistent in every CMSIS-\/\+RTOS. 
\end{DoxyNote}
\Hypertarget{cmsis__os_8c_a4f80ea3dd0140a782dc3e79fc7d1cba6}\index{cmsis\_os.c@{cmsis\_os.c}!osMessageAvailableSpace@{osMessageAvailableSpace}}
\index{osMessageAvailableSpace@{osMessageAvailableSpace}!cmsis\_os.c@{cmsis\_os.c}}
\doxysubsubsection{\texorpdfstring{osMessageAvailableSpace()}{osMessageAvailableSpace()}}
{\footnotesize\ttfamily \label{cmsis__os_8c_a4f80ea3dd0140a782dc3e79fc7d1cba6} 
uint32\+\_\+t os\+Message\+Available\+Space (\begin{DoxyParamCaption}\item[{\mbox{\hyperlink{cmsis__os_8h_a8c191fd2b1369c8942873496a186a022}{os\+Message\+QId}}}]{queue\+\_\+id}{}\end{DoxyParamCaption})}

Get the available space in a message queue. 

\begin{DoxyParams}{Paramètres}
{\em queue\+\_\+id} & message queue ID obtained with \doxylink{cmsis__os_8c_af3b9345cf426304d46565152bc26fb78}{os\+Message\+Create}. \\
\hline
\end{DoxyParams}

\begin{DoxyRetVals}{Valeurs retournées}
{\em available} & space in a message queue. \\
\hline
\end{DoxyRetVals}
\Hypertarget{cmsis__os_8c_af3b9345cf426304d46565152bc26fb78}\index{cmsis\_os.c@{cmsis\_os.c}!osMessageCreate@{osMessageCreate}}
\index{osMessageCreate@{osMessageCreate}!cmsis\_os.c@{cmsis\_os.c}}
\doxysubsubsection{\texorpdfstring{osMessageCreate()}{osMessageCreate()}}
{\footnotesize\ttfamily \label{cmsis__os_8c_af3b9345cf426304d46565152bc26fb78} 
\mbox{\hyperlink{cmsis__os_8h_a8c191fd2b1369c8942873496a186a022}{os\+Message\+QId}} os\+Message\+Create (\begin{DoxyParamCaption}\item[{const \mbox{\hyperlink{cmsis__os_8h_a552ffc97e37e403acff6a59793ad26eb}{os\+Message\+QDef\+\_\+t}} \texorpdfstring{$\ast$}{*}}]{queue\+\_\+def}{, }\item[{\mbox{\hyperlink{cmsis__os_8h_a217fdd2811440d39a6e8c868a0b8ec82}{os\+Thread\+Id}}}]{thread\+\_\+id}{}\end{DoxyParamCaption})}

Create and Initialize a Message Queue. 

\begin{DoxyParams}{Paramètres}
{\em queue\+\_\+def} & queue definition referenced with \doxylink{cmsis__os_8h_a2d446a0b4bb90bf05d6f92eedeaabc97}{os\+MessageQ}. \\
\hline
{\em thread\+\_\+id} & thread ID (obtained by \doxylink{cmsis__os_8c_ac59b5713cb083702dce759c73fd90dff}{os\+Thread\+Create} or \doxylink{cmsis__os_8c_ab1df2a28925862ef8f9cf4e1c995c5a7}{os\+Thread\+Get\+Id}) or NULL. \\
\hline
\end{DoxyParams}

\begin{DoxyRetVals}{Valeurs retournées}
{\em message} & queue ID for reference by other functions or NULL in case of error. \\
\hline
\end{DoxyRetVals}
\begin{DoxyNote}{Note}
MUST REMAIN UNCHANGED\+: {\bfseries{os\+Message\+Create}} shall be consistent in every CMSIS-\/\+RTOS. 
\end{DoxyNote}
\Hypertarget{cmsis__os_8c_aa6eff4b4ee9e73ab881840eaf329c469}\index{cmsis\_os.c@{cmsis\_os.c}!osMessageDelete@{osMessageDelete}}
\index{osMessageDelete@{osMessageDelete}!cmsis\_os.c@{cmsis\_os.c}}
\doxysubsubsection{\texorpdfstring{osMessageDelete()}{osMessageDelete()}}
{\footnotesize\ttfamily \label{cmsis__os_8c_aa6eff4b4ee9e73ab881840eaf329c469} 
\mbox{\hyperlink{cmsis__os_8h_ae2e091fefc4c767117727bd5aba4d99e}{os\+Status}} os\+Message\+Delete (\begin{DoxyParamCaption}\item[{\mbox{\hyperlink{cmsis__os_8h_a8c191fd2b1369c8942873496a186a022}{os\+Message\+QId}}}]{queue\+\_\+id}{}\end{DoxyParamCaption})}

Delete a Message Queue. 

\begin{DoxyParams}{Paramètres}
{\em queue\+\_\+id} & message queue ID obtained with \doxylink{cmsis__os_8c_af3b9345cf426304d46565152bc26fb78}{os\+Message\+Create}. \\
\hline
\end{DoxyParams}

\begin{DoxyRetVals}{Valeurs retournées}
{\em status} & code that indicates the execution status of the function. \\
\hline
\end{DoxyRetVals}
\Hypertarget{cmsis__os_8c_a6c6892b8f2296cca6becd57ca2d7e1ae}\index{cmsis\_os.c@{cmsis\_os.c}!osMessageGet@{osMessageGet}}
\index{osMessageGet@{osMessageGet}!cmsis\_os.c@{cmsis\_os.c}}
\doxysubsubsection{\texorpdfstring{osMessageGet()}{osMessageGet()}}
{\footnotesize\ttfamily \label{cmsis__os_8c_a6c6892b8f2296cca6becd57ca2d7e1ae} 
\mbox{\hyperlink{structos_event}{os\+Event}} os\+Message\+Get (\begin{DoxyParamCaption}\item[{\mbox{\hyperlink{cmsis__os_8h_a8c191fd2b1369c8942873496a186a022}{os\+Message\+QId}}}]{queue\+\_\+id}{, }\item[{uint32\+\_\+t}]{millisec}{}\end{DoxyParamCaption})}

Get a Message or Wait for a Message from a Queue. 

\begin{DoxyParams}{Paramètres}
{\em queue\+\_\+id} & message queue ID obtained with \doxylink{cmsis__os_8c_af3b9345cf426304d46565152bc26fb78}{os\+Message\+Create}. \\
\hline
{\em millisec} & timeout value or 0 in case of no time-\/out. \\
\hline
\end{DoxyParams}

\begin{DoxyRetVals}{Valeurs retournées}
{\em event} & information that includes status code. \\
\hline
\end{DoxyRetVals}
\begin{DoxyNote}{Note}
MUST REMAIN UNCHANGED\+: {\bfseries{os\+Message\+Get}} shall be consistent in every CMSIS-\/\+RTOS. 
\end{DoxyNote}
\Hypertarget{cmsis__os_8c_aee1081c573fe04809315378a37c0ce23}\index{cmsis\_os.c@{cmsis\_os.c}!osMessagePeek@{osMessagePeek}}
\index{osMessagePeek@{osMessagePeek}!cmsis\_os.c@{cmsis\_os.c}}
\doxysubsubsection{\texorpdfstring{osMessagePeek()}{osMessagePeek()}}
{\footnotesize\ttfamily \label{cmsis__os_8c_aee1081c573fe04809315378a37c0ce23} 
\mbox{\hyperlink{structos_event}{os\+Event}} os\+Message\+Peek (\begin{DoxyParamCaption}\item[{\mbox{\hyperlink{cmsis__os_8h_a8c191fd2b1369c8942873496a186a022}{os\+Message\+QId}}}]{queue\+\_\+id}{, }\item[{uint32\+\_\+t}]{millisec}{}\end{DoxyParamCaption})}

Receive an item from a queue without removing the item from the queue. 

\begin{DoxyParams}{Paramètres}
{\em queue\+\_\+id} & message queue ID obtained with \doxylink{cmsis__os_8c_af3b9345cf426304d46565152bc26fb78}{os\+Message\+Create}. \\
\hline
{\em millisec} & timeout value or 0 in case of no time-\/out. \\
\hline
\end{DoxyParams}

\begin{DoxyRetVals}{Valeurs retournées}
{\em event} & information that includes status code. \\
\hline
\end{DoxyRetVals}
\Hypertarget{cmsis__os_8c_ac0dcf462fc92de8ffaba6cc004514a6d}\index{cmsis\_os.c@{cmsis\_os.c}!osMessagePut@{osMessagePut}}
\index{osMessagePut@{osMessagePut}!cmsis\_os.c@{cmsis\_os.c}}
\doxysubsubsection{\texorpdfstring{osMessagePut()}{osMessagePut()}}
{\footnotesize\ttfamily \label{cmsis__os_8c_ac0dcf462fc92de8ffaba6cc004514a6d} 
\mbox{\hyperlink{cmsis__os_8h_ae2e091fefc4c767117727bd5aba4d99e}{os\+Status}} os\+Message\+Put (\begin{DoxyParamCaption}\item[{\mbox{\hyperlink{cmsis__os_8h_a8c191fd2b1369c8942873496a186a022}{os\+Message\+QId}}}]{queue\+\_\+id}{, }\item[{uint32\+\_\+t}]{info}{, }\item[{uint32\+\_\+t}]{millisec}{}\end{DoxyParamCaption})}

Put a Message to a Queue. 

\begin{DoxyParams}{Paramètres}
{\em queue\+\_\+id} & message queue ID obtained with \doxylink{cmsis__os_8c_af3b9345cf426304d46565152bc26fb78}{os\+Message\+Create}. \\
\hline
{\em info} & message information. \\
\hline
{\em millisec} & timeout value or 0 in case of no time-\/out. \\
\hline
\end{DoxyParams}

\begin{DoxyRetVals}{Valeurs retournées}
{\em status} & code that indicates the execution status of the function. \\
\hline
\end{DoxyRetVals}
\begin{DoxyNote}{Note}
MUST REMAIN UNCHANGED\+: {\bfseries{os\+Message\+Put}} shall be consistent in every CMSIS-\/\+RTOS. 
\end{DoxyNote}
\Hypertarget{cmsis__os_8c_a272501325655aa8bbf36ecd36e38bc56}\index{cmsis\_os.c@{cmsis\_os.c}!osMessageWaiting@{osMessageWaiting}}
\index{osMessageWaiting@{osMessageWaiting}!cmsis\_os.c@{cmsis\_os.c}}
\doxysubsubsection{\texorpdfstring{osMessageWaiting()}{osMessageWaiting()}}
{\footnotesize\ttfamily \label{cmsis__os_8c_a272501325655aa8bbf36ecd36e38bc56} 
uint32\+\_\+t os\+Message\+Waiting (\begin{DoxyParamCaption}\item[{\mbox{\hyperlink{cmsis__os_8h_a8c191fd2b1369c8942873496a186a022}{os\+Message\+QId}}}]{queue\+\_\+id}{}\end{DoxyParamCaption})}

Get the number of messaged stored in a queue. 

\begin{DoxyParams}{Paramètres}
{\em queue\+\_\+id} & message queue ID obtained with \doxylink{cmsis__os_8c_af3b9345cf426304d46565152bc26fb78}{os\+Message\+Create}. \\
\hline
\end{DoxyParams}

\begin{DoxyRetVals}{Valeurs retournées}
{\em number} & of messages stored in a queue. \\
\hline
\end{DoxyRetVals}
\Hypertarget{cmsis__os_8c_a5c9de56e717016e39e788064e9a291cc}\index{cmsis\_os.c@{cmsis\_os.c}!osMutexCreate@{osMutexCreate}}
\index{osMutexCreate@{osMutexCreate}!cmsis\_os.c@{cmsis\_os.c}}
\doxysubsubsection{\texorpdfstring{osMutexCreate()}{osMutexCreate()}}
{\footnotesize\ttfamily \label{cmsis__os_8c_a5c9de56e717016e39e788064e9a291cc} 
\mbox{\hyperlink{cmsis__os_8h_abba580e11219b5ec867b5b26ac0b87f4}{os\+Mutex\+Id}} os\+Mutex\+Create (\begin{DoxyParamCaption}\item[{const \mbox{\hyperlink{cmsis__os_8h_ac2907bdcc057de650ea61777a0e92d11}{os\+Mutex\+Def\+\_\+t}} \texorpdfstring{$\ast$}{*}}]{mutex\+\_\+def}{}\end{DoxyParamCaption})}

Create and Initialize a Mutex object. 

\begin{DoxyParams}{Paramètres}
{\em mutex\+\_\+def} & mutex definition referenced with \doxylink{cmsis__os_8h_a1122a86faa64b4a0880c76cf68d0c934}{os\+Mutex}. \\
\hline
\end{DoxyParams}

\begin{DoxyRetVals}{Valeurs retournées}
{\em mutex} & ID for reference by other functions or NULL in case of error. \\
\hline
\end{DoxyRetVals}
\begin{DoxyNote}{Note}
MUST REMAIN UNCHANGED\+: {\bfseries{os\+Mutex\+Create}} shall be consistent in every CMSIS-\/\+RTOS. 
\end{DoxyNote}
\Hypertarget{cmsis__os_8c_ac27e24135185d51d18f3dabc20910219}\index{cmsis\_os.c@{cmsis\_os.c}!osMutexDelete@{osMutexDelete}}
\index{osMutexDelete@{osMutexDelete}!cmsis\_os.c@{cmsis\_os.c}}
\doxysubsubsection{\texorpdfstring{osMutexDelete()}{osMutexDelete()}}
{\footnotesize\ttfamily \label{cmsis__os_8c_ac27e24135185d51d18f3dabc20910219} 
\mbox{\hyperlink{cmsis__os_8h_ae2e091fefc4c767117727bd5aba4d99e}{os\+Status}} os\+Mutex\+Delete (\begin{DoxyParamCaption}\item[{\mbox{\hyperlink{cmsis__os_8h_abba580e11219b5ec867b5b26ac0b87f4}{os\+Mutex\+Id}}}]{mutex\+\_\+id}{}\end{DoxyParamCaption})}

Delete a Mutex. 

\begin{DoxyParams}{Paramètres}
{\em mutex\+\_\+id} & mutex ID obtained by \doxylink{cmsis__os_8c_a5c9de56e717016e39e788064e9a291cc}{os\+Mutex\+Create}. \\
\hline
\end{DoxyParams}

\begin{DoxyRetVals}{Valeurs retournées}
{\em status} & code that indicates the execution status of the function. \\
\hline
\end{DoxyRetVals}
\begin{DoxyNote}{Note}
MUST REMAIN UNCHANGED\+: {\bfseries{os\+Mutex\+Delete}} shall be consistent in every CMSIS-\/\+RTOS. 
\end{DoxyNote}
\Hypertarget{cmsis__os_8c_a006e4744d741e8e132c3d5bbc295afe1}\index{cmsis\_os.c@{cmsis\_os.c}!osMutexRelease@{osMutexRelease}}
\index{osMutexRelease@{osMutexRelease}!cmsis\_os.c@{cmsis\_os.c}}
\doxysubsubsection{\texorpdfstring{osMutexRelease()}{osMutexRelease()}}
{\footnotesize\ttfamily \label{cmsis__os_8c_a006e4744d741e8e132c3d5bbc295afe1} 
\mbox{\hyperlink{cmsis__os_8h_ae2e091fefc4c767117727bd5aba4d99e}{os\+Status}} os\+Mutex\+Release (\begin{DoxyParamCaption}\item[{\mbox{\hyperlink{cmsis__os_8h_abba580e11219b5ec867b5b26ac0b87f4}{os\+Mutex\+Id}}}]{mutex\+\_\+id}{}\end{DoxyParamCaption})}

Release a Mutex that was obtained by \doxylink{cmsis__os_8c_a5e1752b73f573ee015dbd9ef1edaba13}{os\+Mutex\+Wait}. 

\begin{DoxyParams}{Paramètres}
{\em mutex\+\_\+id} & mutex ID obtained by \doxylink{cmsis__os_8c_a5c9de56e717016e39e788064e9a291cc}{os\+Mutex\+Create}. \\
\hline
\end{DoxyParams}

\begin{DoxyRetVals}{Valeurs retournées}
{\em status} & code that indicates the execution status of the function. \\
\hline
\end{DoxyRetVals}
\begin{DoxyNote}{Note}
MUST REMAIN UNCHANGED\+: {\bfseries{os\+Mutex\+Release}} shall be consistent in every CMSIS-\/\+RTOS. 
\end{DoxyNote}
\Hypertarget{cmsis__os_8c_a5e1752b73f573ee015dbd9ef1edaba13}\index{cmsis\_os.c@{cmsis\_os.c}!osMutexWait@{osMutexWait}}
\index{osMutexWait@{osMutexWait}!cmsis\_os.c@{cmsis\_os.c}}
\doxysubsubsection{\texorpdfstring{osMutexWait()}{osMutexWait()}}
{\footnotesize\ttfamily \label{cmsis__os_8c_a5e1752b73f573ee015dbd9ef1edaba13} 
\mbox{\hyperlink{cmsis__os_8h_ae2e091fefc4c767117727bd5aba4d99e}{os\+Status}} os\+Mutex\+Wait (\begin{DoxyParamCaption}\item[{\mbox{\hyperlink{cmsis__os_8h_abba580e11219b5ec867b5b26ac0b87f4}{os\+Mutex\+Id}}}]{mutex\+\_\+id}{, }\item[{uint32\+\_\+t}]{millisec}{}\end{DoxyParamCaption})}

Wait until a Mutex becomes available. 

\begin{DoxyParams}{Paramètres}
{\em mutex\+\_\+id} & mutex ID obtained by \doxylink{cmsis__os_8c_a5c9de56e717016e39e788064e9a291cc}{os\+Mutex\+Create}. \\
\hline
{\em millisec} & timeout value or 0 in case of no time-\/out. \\
\hline
\end{DoxyParams}

\begin{DoxyRetVals}{Valeurs retournées}
{\em status} & code that indicates the execution status of the function. \\
\hline
\end{DoxyRetVals}
\begin{DoxyNote}{Note}
MUST REMAIN UNCHANGED\+: {\bfseries{os\+Mutex\+Wait}} shall be consistent in every CMSIS-\/\+RTOS. 
\end{DoxyNote}
\Hypertarget{cmsis__os_8c_aa0b2994f1a866c19e0d11e6e0d44f543}\index{cmsis\_os.c@{cmsis\_os.c}!osPoolAlloc@{osPoolAlloc}}
\index{osPoolAlloc@{osPoolAlloc}!cmsis\_os.c@{cmsis\_os.c}}
\doxysubsubsection{\texorpdfstring{osPoolAlloc()}{osPoolAlloc()}}
{\footnotesize\ttfamily \label{cmsis__os_8c_aa0b2994f1a866c19e0d11e6e0d44f543} 
void \texorpdfstring{$\ast$}{*} os\+Pool\+Alloc (\begin{DoxyParamCaption}\item[{\mbox{\hyperlink{cmsis__os_8h_a08d2e20fd9bbd96220fe068d420f3686}{os\+Pool\+Id}}}]{pool\+\_\+id}{}\end{DoxyParamCaption})}

Allocate a memory block from a memory pool. 

\begin{DoxyParams}{Paramètres}
{\em pool\+\_\+id} & memory pool ID obtain referenced with \doxylink{cmsis__os_8c_a34af5c4f4ab38f4138ea7f1f9ece3a1a}{os\+Pool\+Create}. \\
\hline
\end{DoxyParams}

\begin{DoxyRetVals}{Valeurs retournées}
{\em address} & of the allocated memory block or NULL in case of no memory available. \\
\hline
\end{DoxyRetVals}
\begin{DoxyNote}{Note}
MUST REMAIN UNCHANGED\+: {\bfseries{os\+Pool\+Alloc}} shall be consistent in every CMSIS-\/\+RTOS. 
\end{DoxyNote}
\Hypertarget{cmsis__os_8c_a9f129fcad4730fbd1048ad4fa262f36a}\index{cmsis\_os.c@{cmsis\_os.c}!osPoolCAlloc@{osPoolCAlloc}}
\index{osPoolCAlloc@{osPoolCAlloc}!cmsis\_os.c@{cmsis\_os.c}}
\doxysubsubsection{\texorpdfstring{osPoolCAlloc()}{osPoolCAlloc()}}
{\footnotesize\ttfamily \label{cmsis__os_8c_a9f129fcad4730fbd1048ad4fa262f36a} 
void \texorpdfstring{$\ast$}{*} os\+Pool\+CAlloc (\begin{DoxyParamCaption}\item[{\mbox{\hyperlink{cmsis__os_8h_a08d2e20fd9bbd96220fe068d420f3686}{os\+Pool\+Id}}}]{pool\+\_\+id}{}\end{DoxyParamCaption})}

Allocate a memory block from a memory pool and set memory block to zero. 

\begin{DoxyParams}{Paramètres}
{\em pool\+\_\+id} & memory pool ID obtain referenced with \doxylink{cmsis__os_8c_a34af5c4f4ab38f4138ea7f1f9ece3a1a}{os\+Pool\+Create}. \\
\hline
\end{DoxyParams}

\begin{DoxyRetVals}{Valeurs retournées}
{\em address} & of the allocated memory block or NULL in case of no memory available. \\
\hline
\end{DoxyRetVals}
\begin{DoxyNote}{Note}
MUST REMAIN UNCHANGED\+: {\bfseries{os\+Pool\+CAlloc}} shall be consistent in every CMSIS-\/\+RTOS. 
\end{DoxyNote}
\Hypertarget{cmsis__os_8c_a34af5c4f4ab38f4138ea7f1f9ece3a1a}\index{cmsis\_os.c@{cmsis\_os.c}!osPoolCreate@{osPoolCreate}}
\index{osPoolCreate@{osPoolCreate}!cmsis\_os.c@{cmsis\_os.c}}
\doxysubsubsection{\texorpdfstring{osPoolCreate()}{osPoolCreate()}}
{\footnotesize\ttfamily \label{cmsis__os_8c_a34af5c4f4ab38f4138ea7f1f9ece3a1a} 
\mbox{\hyperlink{cmsis__os_8h_a08d2e20fd9bbd96220fe068d420f3686}{os\+Pool\+Id}} os\+Pool\+Create (\begin{DoxyParamCaption}\item[{const \mbox{\hyperlink{cmsis__os_8h_ac47b811c41974c0bb74521a50c7983b7}{os\+Pool\+Def\+\_\+t}} \texorpdfstring{$\ast$}{*}}]{pool\+\_\+def}{}\end{DoxyParamCaption})}

Create and Initialize a memory pool. 

\begin{DoxyParams}{Paramètres}
{\em pool\+\_\+def} & memory pool definition referenced with \doxylink{cmsis__os_8h_a5f0b204a82327533d420210125c90697}{os\+Pool}. \\
\hline
\end{DoxyParams}

\begin{DoxyRetVals}{Valeurs retournées}
{\em memory} & pool ID for reference by other functions or NULL in case of error. \\
\hline
\end{DoxyRetVals}
\begin{DoxyNote}{Note}
MUST REMAIN UNCHANGED\+: {\bfseries{os\+Pool\+Create}} shall be consistent in every CMSIS-\/\+RTOS. 
\end{DoxyNote}
\Hypertarget{cmsis__os_8c_a4a861e9c469c9d0daf5721bf174f8e54}\index{cmsis\_os.c@{cmsis\_os.c}!osPoolFree@{osPoolFree}}
\index{osPoolFree@{osPoolFree}!cmsis\_os.c@{cmsis\_os.c}}
\doxysubsubsection{\texorpdfstring{osPoolFree()}{osPoolFree()}}
{\footnotesize\ttfamily \label{cmsis__os_8c_a4a861e9c469c9d0daf5721bf174f8e54} 
\mbox{\hyperlink{cmsis__os_8h_ae2e091fefc4c767117727bd5aba4d99e}{os\+Status}} os\+Pool\+Free (\begin{DoxyParamCaption}\item[{\mbox{\hyperlink{cmsis__os_8h_a08d2e20fd9bbd96220fe068d420f3686}{os\+Pool\+Id}}}]{pool\+\_\+id}{, }\item[{void \texorpdfstring{$\ast$}{*}}]{block}{}\end{DoxyParamCaption})}

Return an allocated memory block back to a specific memory pool. 

\begin{DoxyParams}{Paramètres}
{\em pool\+\_\+id} & memory pool ID obtain referenced with \doxylink{cmsis__os_8c_a34af5c4f4ab38f4138ea7f1f9ece3a1a}{os\+Pool\+Create}. \\
\hline
{\em block} & address of the allocated memory block that is returned to the memory pool. \\
\hline
\end{DoxyParams}

\begin{DoxyRetVals}{Valeurs retournées}
{\em status} & code that indicates the execution status of the function. \\
\hline
\end{DoxyRetVals}
\begin{DoxyNote}{Note}
MUST REMAIN UNCHANGED\+: {\bfseries{os\+Pool\+Free}} shall be consistent in every CMSIS-\/\+RTOS. 
\end{DoxyNote}
\Hypertarget{cmsis__os_8c_a09a8e658872a88d284f8143bcb62cff6}\index{cmsis\_os.c@{cmsis\_os.c}!osRecursiveMutexCreate@{osRecursiveMutexCreate}}
\index{osRecursiveMutexCreate@{osRecursiveMutexCreate}!cmsis\_os.c@{cmsis\_os.c}}
\doxysubsubsection{\texorpdfstring{osRecursiveMutexCreate()}{osRecursiveMutexCreate()}}
{\footnotesize\ttfamily \label{cmsis__os_8c_a09a8e658872a88d284f8143bcb62cff6} 
\mbox{\hyperlink{cmsis__os_8h_abba580e11219b5ec867b5b26ac0b87f4}{os\+Mutex\+Id}} os\+Recursive\+Mutex\+Create (\begin{DoxyParamCaption}\item[{const \mbox{\hyperlink{cmsis__os_8h_ac2907bdcc057de650ea61777a0e92d11}{os\+Mutex\+Def\+\_\+t}} \texorpdfstring{$\ast$}{*}}]{mutex\+\_\+def}{}\end{DoxyParamCaption})}

Create and Initialize a Recursive Mutex. 

\begin{DoxyParams}{Paramètres}
{\em mutex\+\_\+def} & mutex definition referenced with \doxylink{cmsis__os_8h_a1122a86faa64b4a0880c76cf68d0c934}{os\+Mutex}. \\
\hline
\end{DoxyParams}

\begin{DoxyRetVals}{Valeurs retournées}
{\em mutex} & ID for reference by other functions or NULL in case of error.. \\
\hline
\end{DoxyRetVals}
\Hypertarget{cmsis__os_8c_a14c641c81a487a21851555cab5c04531}\index{cmsis\_os.c@{cmsis\_os.c}!osRecursiveMutexRelease@{osRecursiveMutexRelease}}
\index{osRecursiveMutexRelease@{osRecursiveMutexRelease}!cmsis\_os.c@{cmsis\_os.c}}
\doxysubsubsection{\texorpdfstring{osRecursiveMutexRelease()}{osRecursiveMutexRelease()}}
{\footnotesize\ttfamily \label{cmsis__os_8c_a14c641c81a487a21851555cab5c04531} 
\mbox{\hyperlink{cmsis__os_8h_ae2e091fefc4c767117727bd5aba4d99e}{os\+Status}} os\+Recursive\+Mutex\+Release (\begin{DoxyParamCaption}\item[{\mbox{\hyperlink{cmsis__os_8h_abba580e11219b5ec867b5b26ac0b87f4}{os\+Mutex\+Id}}}]{mutex\+\_\+id}{}\end{DoxyParamCaption})}

Release a Recursive Mutex. 

\begin{DoxyParams}{Paramètres}
{\em mutex\+\_\+id} & mutex ID obtained by \doxylink{cmsis__os_8c_a09a8e658872a88d284f8143bcb62cff6}{os\+Recursive\+Mutex\+Create}. \\
\hline
\end{DoxyParams}

\begin{DoxyRetVals}{Valeurs retournées}
{\em status} & code that indicates the execution status of the function. \\
\hline
\end{DoxyRetVals}
\Hypertarget{cmsis__os_8c_a479c5c0d01b4f43854761026d2054b30}\index{cmsis\_os.c@{cmsis\_os.c}!osRecursiveMutexWait@{osRecursiveMutexWait}}
\index{osRecursiveMutexWait@{osRecursiveMutexWait}!cmsis\_os.c@{cmsis\_os.c}}
\doxysubsubsection{\texorpdfstring{osRecursiveMutexWait()}{osRecursiveMutexWait()}}
{\footnotesize\ttfamily \label{cmsis__os_8c_a479c5c0d01b4f43854761026d2054b30} 
\mbox{\hyperlink{cmsis__os_8h_ae2e091fefc4c767117727bd5aba4d99e}{os\+Status}} os\+Recursive\+Mutex\+Wait (\begin{DoxyParamCaption}\item[{\mbox{\hyperlink{cmsis__os_8h_abba580e11219b5ec867b5b26ac0b87f4}{os\+Mutex\+Id}}}]{mutex\+\_\+id}{, }\item[{uint32\+\_\+t}]{millisec}{}\end{DoxyParamCaption})}

Release a Recursive Mutex. 

\begin{DoxyParams}{Paramètres}
{\em mutex\+\_\+id} & mutex ID obtained by \doxylink{cmsis__os_8c_a09a8e658872a88d284f8143bcb62cff6}{os\+Recursive\+Mutex\+Create}. \\
\hline
{\em millisec} & timeout value or 0 in case of no time-\/out. \\
\hline
\end{DoxyParams}

\begin{DoxyRetVals}{Valeurs retournées}
{\em status} & code that indicates the execution status of the function. \\
\hline
\end{DoxyRetVals}
\Hypertarget{cmsis__os_8c_a97381e8e55cd47cec390bf57c96d6edb}\index{cmsis\_os.c@{cmsis\_os.c}!osSemaphoreCreate@{osSemaphoreCreate}}
\index{osSemaphoreCreate@{osSemaphoreCreate}!cmsis\_os.c@{cmsis\_os.c}}
\doxysubsubsection{\texorpdfstring{osSemaphoreCreate()}{osSemaphoreCreate()}}
{\footnotesize\ttfamily \label{cmsis__os_8c_a97381e8e55cd47cec390bf57c96d6edb} 
\mbox{\hyperlink{cmsis__os_8h_a954e9c06583b05ae736d07e4e40097d5}{os\+Semaphore\+Id}} os\+Semaphore\+Create (\begin{DoxyParamCaption}\item[{const \mbox{\hyperlink{cmsis__os_8h_acf4486afa668a4499003e1a750eb8ab1}{os\+Semaphore\+Def\+\_\+t}} \texorpdfstring{$\ast$}{*}}]{semaphore\+\_\+def}{, }\item[{int32\+\_\+t}]{count}{}\end{DoxyParamCaption})}

Create and Initialize a Semaphore object used for managing resources. 

\begin{DoxyParams}{Paramètres}
{\em semaphore\+\_\+def} & semaphore definition referenced with \doxylink{cmsis__os_8h_a03761ee8d2c3cd4544e18364ab301dac}{os\+Semaphore}. \\
\hline
{\em count} & number of available resources. \\
\hline
\end{DoxyParams}

\begin{DoxyRetVals}{Valeurs retournées}
{\em semaphore} & ID for reference by other functions or NULL in case of error. \\
\hline
\end{DoxyRetVals}
\begin{DoxyNote}{Note}
MUST REMAIN UNCHANGED\+: {\bfseries{os\+Semaphore\+Create}} shall be consistent in every CMSIS-\/\+RTOS. 
\end{DoxyNote}
\Hypertarget{cmsis__os_8c_abae2801ac2c096f6e8c69a264908f595}\index{cmsis\_os.c@{cmsis\_os.c}!osSemaphoreDelete@{osSemaphoreDelete}}
\index{osSemaphoreDelete@{osSemaphoreDelete}!cmsis\_os.c@{cmsis\_os.c}}
\doxysubsubsection{\texorpdfstring{osSemaphoreDelete()}{osSemaphoreDelete()}}
{\footnotesize\ttfamily \label{cmsis__os_8c_abae2801ac2c096f6e8c69a264908f595} 
\mbox{\hyperlink{cmsis__os_8h_ae2e091fefc4c767117727bd5aba4d99e}{os\+Status}} os\+Semaphore\+Delete (\begin{DoxyParamCaption}\item[{\mbox{\hyperlink{cmsis__os_8h_a954e9c06583b05ae736d07e4e40097d5}{os\+Semaphore\+Id}}}]{semaphore\+\_\+id}{}\end{DoxyParamCaption})}

Delete a Semaphore. 

\begin{DoxyParams}{Paramètres}
{\em semaphore\+\_\+id} & semaphore object referenced with \doxylink{cmsis__os_8h_a03761ee8d2c3cd4544e18364ab301dac}{os\+Semaphore}. \\
\hline
\end{DoxyParams}

\begin{DoxyRetVals}{Valeurs retournées}
{\em status} & code that indicates the execution status of the function. \\
\hline
\end{DoxyRetVals}
\begin{DoxyNote}{Note}
MUST REMAIN UNCHANGED\+: {\bfseries{os\+Semaphore\+Delete}} shall be consistent in every CMSIS-\/\+RTOS. 
\end{DoxyNote}
\Hypertarget{cmsis__os_8c_a5aaec061a877326be39a4998f7690567}\index{cmsis\_os.c@{cmsis\_os.c}!osSemaphoreGetCount@{osSemaphoreGetCount}}
\index{osSemaphoreGetCount@{osSemaphoreGetCount}!cmsis\_os.c@{cmsis\_os.c}}
\doxysubsubsection{\texorpdfstring{osSemaphoreGetCount()}{osSemaphoreGetCount()}}
{\footnotesize\ttfamily \label{cmsis__os_8c_a5aaec061a877326be39a4998f7690567} 
uint32\+\_\+t os\+Semaphore\+Get\+Count (\begin{DoxyParamCaption}\item[{\mbox{\hyperlink{cmsis__os_8h_a954e9c06583b05ae736d07e4e40097d5}{os\+Semaphore\+Id}}}]{semaphore\+\_\+id}{}\end{DoxyParamCaption})}

Returns the current count value of a counting semaphore. 

\begin{DoxyParams}{Paramètres}
{\em semaphore\+\_\+id} & semaphore\+\_\+id ID obtained by \doxylink{cmsis__os_8c_a97381e8e55cd47cec390bf57c96d6edb}{os\+Semaphore\+Create}. \\
\hline
\end{DoxyParams}

\begin{DoxyRetVals}{Valeurs retournées}
{\em count} & value \\
\hline
\end{DoxyRetVals}
\Hypertarget{cmsis__os_8c_ab108914997c49e14d8ff1ae0d1988ca0}\index{cmsis\_os.c@{cmsis\_os.c}!osSemaphoreRelease@{osSemaphoreRelease}}
\index{osSemaphoreRelease@{osSemaphoreRelease}!cmsis\_os.c@{cmsis\_os.c}}
\doxysubsubsection{\texorpdfstring{osSemaphoreRelease()}{osSemaphoreRelease()}}
{\footnotesize\ttfamily \label{cmsis__os_8c_ab108914997c49e14d8ff1ae0d1988ca0} 
\mbox{\hyperlink{cmsis__os_8h_ae2e091fefc4c767117727bd5aba4d99e}{os\+Status}} os\+Semaphore\+Release (\begin{DoxyParamCaption}\item[{\mbox{\hyperlink{cmsis__os_8h_a954e9c06583b05ae736d07e4e40097d5}{os\+Semaphore\+Id}}}]{semaphore\+\_\+id}{}\end{DoxyParamCaption})}

Release a Semaphore token. 

\begin{DoxyParams}{Paramètres}
{\em semaphore\+\_\+id} & semaphore object referenced with \doxylink{cmsis__os_8h_a03761ee8d2c3cd4544e18364ab301dac}{os\+Semaphore}. \\
\hline
\end{DoxyParams}

\begin{DoxyRetVals}{Valeurs retournées}
{\em status} & code that indicates the execution status of the function. \\
\hline
\end{DoxyRetVals}
\begin{DoxyNote}{Note}
MUST REMAIN UNCHANGED\+: {\bfseries{os\+Semaphore\+Release}} shall be consistent in every CMSIS-\/\+RTOS. 
\end{DoxyNote}
\Hypertarget{cmsis__os_8c_acc15b0fc8ce1167fe43da33042e62098}\index{cmsis\_os.c@{cmsis\_os.c}!osSemaphoreWait@{osSemaphoreWait}}
\index{osSemaphoreWait@{osSemaphoreWait}!cmsis\_os.c@{cmsis\_os.c}}
\doxysubsubsection{\texorpdfstring{osSemaphoreWait()}{osSemaphoreWait()}}
{\footnotesize\ttfamily \label{cmsis__os_8c_acc15b0fc8ce1167fe43da33042e62098} 
int32\+\_\+t os\+Semaphore\+Wait (\begin{DoxyParamCaption}\item[{\mbox{\hyperlink{cmsis__os_8h_a954e9c06583b05ae736d07e4e40097d5}{os\+Semaphore\+Id}}}]{semaphore\+\_\+id}{, }\item[{uint32\+\_\+t}]{millisec}{}\end{DoxyParamCaption})}

Wait until a Semaphore token becomes available. 

\begin{DoxyParams}{Paramètres}
{\em semaphore\+\_\+id} & semaphore object referenced with \doxylink{cmsis__os_8h_a03761ee8d2c3cd4544e18364ab301dac}{os\+Semaphore}. \\
\hline
{\em millisec} & timeout value or 0 in case of no time-\/out. \\
\hline
\end{DoxyParams}

\begin{DoxyRetVals}{Valeurs retournées}
{\em number} & of available tokens, or -\/1 in case of incorrect parameters. \\
\hline
\end{DoxyRetVals}
\begin{DoxyNote}{Note}
MUST REMAIN UNCHANGED\+: {\bfseries{os\+Semaphore\+Wait}} shall be consistent in every CMSIS-\/\+RTOS. 
\end{DoxyNote}
\Hypertarget{cmsis__os_8c_afcb3a9bd9a3c4c99f2f86d5d33faffd8}\index{cmsis\_os.c@{cmsis\_os.c}!osSignalClear@{osSignalClear}}
\index{osSignalClear@{osSignalClear}!cmsis\_os.c@{cmsis\_os.c}}
\doxysubsubsection{\texorpdfstring{osSignalClear()}{osSignalClear()}}
{\footnotesize\ttfamily \label{cmsis__os_8c_afcb3a9bd9a3c4c99f2f86d5d33faffd8} 
int32\+\_\+t os\+Signal\+Clear (\begin{DoxyParamCaption}\item[{\mbox{\hyperlink{cmsis__os_8h_a217fdd2811440d39a6e8c868a0b8ec82}{os\+Thread\+Id}}}]{thread\+\_\+id}{, }\item[{int32\+\_\+t}]{signal}{}\end{DoxyParamCaption})}

Clear the specified Signal Flags of an active thread. 

\begin{DoxyParams}{Paramètres}
{\em thread\+\_\+id} & thread ID obtained by \doxylink{cmsis__os_8c_ac59b5713cb083702dce759c73fd90dff}{os\+Thread\+Create} or \doxylink{cmsis__os_8c_ab1df2a28925862ef8f9cf4e1c995c5a7}{os\+Thread\+Get\+Id}. \\
\hline
{\em signals} & specifies the signal flags of the thread that shall be cleared. \\
\hline
\end{DoxyParams}

\begin{DoxyRetVals}{Valeurs retournées}
{\em previous} & signal flags of the specified thread or 0x80000000 in case of incorrect parameters. \\
\hline
\end{DoxyRetVals}
\begin{DoxyNote}{Note}
MUST REMAIN UNCHANGED\+: {\bfseries{os\+Signal\+Clear}} shall be consistent in every CMSIS-\/\+RTOS. 
\end{DoxyNote}
\Hypertarget{cmsis__os_8c_a029340f7007656c06fdb8eeeae7b056e}\index{cmsis\_os.c@{cmsis\_os.c}!osSignalSet@{osSignalSet}}
\index{osSignalSet@{osSignalSet}!cmsis\_os.c@{cmsis\_os.c}}
\doxysubsubsection{\texorpdfstring{osSignalSet()}{osSignalSet()}}
{\footnotesize\ttfamily \label{cmsis__os_8c_a029340f7007656c06fdb8eeeae7b056e} 
int32\+\_\+t os\+Signal\+Set (\begin{DoxyParamCaption}\item[{\mbox{\hyperlink{cmsis__os_8h_a217fdd2811440d39a6e8c868a0b8ec82}{os\+Thread\+Id}}}]{thread\+\_\+id}{, }\item[{int32\+\_\+t}]{signal}{}\end{DoxyParamCaption})}

Set the specified Signal Flags of an active thread. 

\begin{DoxyParams}{Paramètres}
{\em thread\+\_\+id} & thread ID obtained by \doxylink{cmsis__os_8c_ac59b5713cb083702dce759c73fd90dff}{os\+Thread\+Create} or \doxylink{cmsis__os_8c_ab1df2a28925862ef8f9cf4e1c995c5a7}{os\+Thread\+Get\+Id}. \\
\hline
{\em signals} & specifies the signal flags of the thread that should be set. \\
\hline
\end{DoxyParams}

\begin{DoxyRetVals}{Valeurs retournées}
{\em previous} & signal flags of the specified thread or 0x80000000 in case of incorrect parameters. \\
\hline
\end{DoxyRetVals}
\begin{DoxyNote}{Note}
MUST REMAIN UNCHANGED\+: {\bfseries{os\+Signal\+Set}} shall be consistent in every CMSIS-\/\+RTOS. 
\end{DoxyNote}
\Hypertarget{cmsis__os_8c_a38860acda96df47da6923348d96fc4c9}\index{cmsis\_os.c@{cmsis\_os.c}!osSignalWait@{osSignalWait}}
\index{osSignalWait@{osSignalWait}!cmsis\_os.c@{cmsis\_os.c}}
\doxysubsubsection{\texorpdfstring{osSignalWait()}{osSignalWait()}}
{\footnotesize\ttfamily \label{cmsis__os_8c_a38860acda96df47da6923348d96fc4c9} 
\mbox{\hyperlink{structos_event}{os\+Event}} os\+Signal\+Wait (\begin{DoxyParamCaption}\item[{int32\+\_\+t}]{signals}{, }\item[{uint32\+\_\+t}]{millisec}{}\end{DoxyParamCaption})}

Wait for one or more Signal Flags to become signaled for the current {\bfseries{RUNNING}} thread. 

\begin{DoxyParams}{Paramètres}
{\em signals} & wait until all specified signal flags set or 0 for any single signal flag. \\
\hline
{\em millisec} & timeout value or 0 in case of no time-\/out. \\
\hline
\end{DoxyParams}

\begin{DoxyRetVals}{Valeurs retournées}
{\em event} & flag information or error code. \\
\hline
\end{DoxyRetVals}
\begin{DoxyNote}{Note}
MUST REMAIN UNCHANGED\+: {\bfseries{os\+Signal\+Wait}} shall be consistent in every CMSIS-\/\+RTOS. 
\end{DoxyNote}
\Hypertarget{cmsis__os_8c_ab169d629ebefc57e030b324d4cce9eea}\index{cmsis\_os.c@{cmsis\_os.c}!osSystickHandler@{osSystickHandler}}
\index{osSystickHandler@{osSystickHandler}!cmsis\_os.c@{cmsis\_os.c}}
\doxysubsubsection{\texorpdfstring{osSystickHandler()}{osSystickHandler()}}
{\footnotesize\ttfamily \label{cmsis__os_8c_ab169d629ebefc57e030b324d4cce9eea} 
void os\+Systick\+Handler (\begin{DoxyParamCaption}\item[{void}]{}{}\end{DoxyParamCaption})}

Handles the tick increment. 

\begin{DoxyParams}{Paramètres}
{\em none.} & \\
\hline
\end{DoxyParams}

\begin{DoxyRetVals}{Valeurs retournées}
{\em none.} & \\
\hline
\end{DoxyRetVals}
\Hypertarget{cmsis__os_8c_ac59b5713cb083702dce759c73fd90dff}\index{cmsis\_os.c@{cmsis\_os.c}!osThreadCreate@{osThreadCreate}}
\index{osThreadCreate@{osThreadCreate}!cmsis\_os.c@{cmsis\_os.c}}
\doxysubsubsection{\texorpdfstring{osThreadCreate()}{osThreadCreate()}}
{\footnotesize\ttfamily \label{cmsis__os_8c_ac59b5713cb083702dce759c73fd90dff} 
\mbox{\hyperlink{cmsis__os_8h_a217fdd2811440d39a6e8c868a0b8ec82}{os\+Thread\+Id}} os\+Thread\+Create (\begin{DoxyParamCaption}\item[{const \mbox{\hyperlink{cmsis__os_8h_a92f46bd508dcc685135882e2cf37ac8c}{os\+Thread\+Def\+\_\+t}} \texorpdfstring{$\ast$}{*}}]{thread\+\_\+def}{, }\item[{void \texorpdfstring{$\ast$}{*}}]{argument}{}\end{DoxyParamCaption})}

Create a thread and add it to Active Threads and set it to state READY. 

\begin{DoxyParams}{Paramètres}
{\em thread\+\_\+def} & thread definition referenced with \doxylink{cmsis__os_8h_af0c7c6b5e09f8be198312144b5c9e453}{os\+Thread}. \\
\hline
{\em argument} & pointer that is passed to the thread function as start argument. \\
\hline
\end{DoxyParams}

\begin{DoxyRetVals}{Valeurs retournées}
{\em thread} & ID for reference by other functions or NULL in case of error. \\
\hline
\end{DoxyRetVals}
\begin{DoxyNote}{Note}
MUST REMAIN UNCHANGED\+: {\bfseries{os\+Thread\+Create}} shall be consistent in every CMSIS-\/\+RTOS. 
\end{DoxyNote}
\Hypertarget{cmsis__os_8c_ab1df2a28925862ef8f9cf4e1c995c5a7}\index{cmsis\_os.c@{cmsis\_os.c}!osThreadGetId@{osThreadGetId}}
\index{osThreadGetId@{osThreadGetId}!cmsis\_os.c@{cmsis\_os.c}}
\doxysubsubsection{\texorpdfstring{osThreadGetId()}{osThreadGetId()}}
{\footnotesize\ttfamily \label{cmsis__os_8c_ab1df2a28925862ef8f9cf4e1c995c5a7} 
\mbox{\hyperlink{cmsis__os_8h_a217fdd2811440d39a6e8c868a0b8ec82}{os\+Thread\+Id}} os\+Thread\+Get\+Id (\begin{DoxyParamCaption}\item[{void}]{}{}\end{DoxyParamCaption})}

Return the thread ID of the current running thread. 

\begin{DoxyRetVals}{Valeurs retournées}
{\em thread} & ID for reference by other functions or NULL in case of error. \\
\hline
\end{DoxyRetVals}
\begin{DoxyNote}{Note}
MUST REMAIN UNCHANGED\+: {\bfseries{os\+Thread\+Get\+Id}} shall be consistent in every CMSIS-\/\+RTOS. 
\end{DoxyNote}
\Hypertarget{cmsis__os_8c_a4299d838978bc2aae5e4350754e6a4e9}\index{cmsis\_os.c@{cmsis\_os.c}!osThreadGetPriority@{osThreadGetPriority}}
\index{osThreadGetPriority@{osThreadGetPriority}!cmsis\_os.c@{cmsis\_os.c}}
\doxysubsubsection{\texorpdfstring{osThreadGetPriority()}{osThreadGetPriority()}}
{\footnotesize\ttfamily \label{cmsis__os_8c_a4299d838978bc2aae5e4350754e6a4e9} 
\mbox{\hyperlink{cmsis__os_8h_a7f2b42f1983b9107775ec2a1c69a849a}{os\+Priority}} os\+Thread\+Get\+Priority (\begin{DoxyParamCaption}\item[{\mbox{\hyperlink{cmsis__os_8h_a217fdd2811440d39a6e8c868a0b8ec82}{os\+Thread\+Id}}}]{thread\+\_\+id}{}\end{DoxyParamCaption})}

Get current priority of an active thread. 

\begin{DoxyParams}{Paramètres}
{\em thread\+\_\+id} & thread ID obtained by \doxylink{cmsis__os_8c_ac59b5713cb083702dce759c73fd90dff}{os\+Thread\+Create} or \doxylink{cmsis__os_8c_ab1df2a28925862ef8f9cf4e1c995c5a7}{os\+Thread\+Get\+Id}. \\
\hline
\end{DoxyParams}

\begin{DoxyRetVals}{Valeurs retournées}
{\em current} & priority value of the thread function. \\
\hline
\end{DoxyRetVals}
\begin{DoxyNote}{Note}
MUST REMAIN UNCHANGED\+: {\bfseries{os\+Thread\+Get\+Priority}} shall be consistent in every CMSIS-\/\+RTOS. 
\end{DoxyNote}
\Hypertarget{cmsis__os_8c_a72dea6af29c3caa97b583da895237697}\index{cmsis\_os.c@{cmsis\_os.c}!osThreadList@{osThreadList}}
\index{osThreadList@{osThreadList}!cmsis\_os.c@{cmsis\_os.c}}
\doxysubsubsection{\texorpdfstring{osThreadList()}{osThreadList()}}
{\footnotesize\ttfamily \label{cmsis__os_8c_a72dea6af29c3caa97b583da895237697} 
\mbox{\hyperlink{cmsis__os_8h_ae2e091fefc4c767117727bd5aba4d99e}{os\+Status}} os\+Thread\+List (\begin{DoxyParamCaption}\item[{uint8\+\_\+t \texorpdfstring{$\ast$}{*}}]{buffer}{}\end{DoxyParamCaption})}

Lists all the current threads, along with their current state and stack usage high water mark. 

\begin{DoxyParams}{Paramètres}
{\em buffer} & A buffer into which the above mentioned details will be written \\
\hline
\end{DoxyParams}

\begin{DoxyRetVals}{Valeurs retournées}
{\em status} & code that indicates the execution status of the function. \\
\hline
\end{DoxyRetVals}
\Hypertarget{cmsis__os_8c_a98905f234a096669566e7b93272b2653}\index{cmsis\_os.c@{cmsis\_os.c}!osThreadResume@{osThreadResume}}
\index{osThreadResume@{osThreadResume}!cmsis\_os.c@{cmsis\_os.c}}
\doxysubsubsection{\texorpdfstring{osThreadResume()}{osThreadResume()}}
{\footnotesize\ttfamily \label{cmsis__os_8c_a98905f234a096669566e7b93272b2653} 
\mbox{\hyperlink{cmsis__os_8h_ae2e091fefc4c767117727bd5aba4d99e}{os\+Status}} os\+Thread\+Resume (\begin{DoxyParamCaption}\item[{\mbox{\hyperlink{cmsis__os_8h_a217fdd2811440d39a6e8c868a0b8ec82}{os\+Thread\+Id}}}]{thread\+\_\+id}{}\end{DoxyParamCaption})}

Resume execution of a suspended thread. 

\begin{DoxyParams}{Paramètres}
{\em thread\+\_\+id} & thread ID obtained by \doxylink{cmsis__os_8c_ac59b5713cb083702dce759c73fd90dff}{os\+Thread\+Create} or \doxylink{cmsis__os_8c_ab1df2a28925862ef8f9cf4e1c995c5a7}{os\+Thread\+Get\+Id}. \\
\hline
\end{DoxyParams}

\begin{DoxyRetVals}{Valeurs retournées}
{\em status} & code that indicates the execution status of the function. \\
\hline
\end{DoxyRetVals}
\Hypertarget{cmsis__os_8c_a909a8098efc243cec5729ac51fdb3bdc}\index{cmsis\_os.c@{cmsis\_os.c}!osThreadResumeAll@{osThreadResumeAll}}
\index{osThreadResumeAll@{osThreadResumeAll}!cmsis\_os.c@{cmsis\_os.c}}
\doxysubsubsection{\texorpdfstring{osThreadResumeAll()}{osThreadResumeAll()}}
{\footnotesize\ttfamily \label{cmsis__os_8c_a909a8098efc243cec5729ac51fdb3bdc} 
\mbox{\hyperlink{cmsis__os_8h_ae2e091fefc4c767117727bd5aba4d99e}{os\+Status}} os\+Thread\+Resume\+All (\begin{DoxyParamCaption}\item[{void}]{}{}\end{DoxyParamCaption})}

Resume execution of a all suspended threads. 

\begin{DoxyRetVals}{Valeurs retournées}
{\em status} & code that indicates the execution status of the function. \\
\hline
\end{DoxyRetVals}
\Hypertarget{cmsis__os_8c_a0dfb90ccf1f6e4b54b9251b12d1cbc8b}\index{cmsis\_os.c@{cmsis\_os.c}!osThreadSetPriority@{osThreadSetPriority}}
\index{osThreadSetPriority@{osThreadSetPriority}!cmsis\_os.c@{cmsis\_os.c}}
\doxysubsubsection{\texorpdfstring{osThreadSetPriority()}{osThreadSetPriority()}}
{\footnotesize\ttfamily \label{cmsis__os_8c_a0dfb90ccf1f6e4b54b9251b12d1cbc8b} 
\mbox{\hyperlink{cmsis__os_8h_ae2e091fefc4c767117727bd5aba4d99e}{os\+Status}} os\+Thread\+Set\+Priority (\begin{DoxyParamCaption}\item[{\mbox{\hyperlink{cmsis__os_8h_a217fdd2811440d39a6e8c868a0b8ec82}{os\+Thread\+Id}}}]{thread\+\_\+id}{, }\item[{\mbox{\hyperlink{cmsis__os_8h_a7f2b42f1983b9107775ec2a1c69a849a}{os\+Priority}}}]{priority}{}\end{DoxyParamCaption})}

Change priority of an active thread. 

\begin{DoxyParams}{Paramètres}
{\em thread\+\_\+id} & thread ID obtained by \doxylink{cmsis__os_8c_ac59b5713cb083702dce759c73fd90dff}{os\+Thread\+Create} or \doxylink{cmsis__os_8c_ab1df2a28925862ef8f9cf4e1c995c5a7}{os\+Thread\+Get\+Id}. \\
\hline
{\em priority} & new priority value for the thread function. \\
\hline
\end{DoxyParams}

\begin{DoxyRetVals}{Valeurs retournées}
{\em status} & code that indicates the execution status of the function. \\
\hline
\end{DoxyRetVals}
\begin{DoxyNote}{Note}
MUST REMAIN UNCHANGED\+: {\bfseries{os\+Thread\+Set\+Priority}} shall be consistent in every CMSIS-\/\+RTOS. 
\end{DoxyNote}
\Hypertarget{cmsis__os_8c_a204bf99a22ca8fe85b1f8028f0268278}\index{cmsis\_os.c@{cmsis\_os.c}!osThreadSuspend@{osThreadSuspend}}
\index{osThreadSuspend@{osThreadSuspend}!cmsis\_os.c@{cmsis\_os.c}}
\doxysubsubsection{\texorpdfstring{osThreadSuspend()}{osThreadSuspend()}}
{\footnotesize\ttfamily \label{cmsis__os_8c_a204bf99a22ca8fe85b1f8028f0268278} 
\mbox{\hyperlink{cmsis__os_8h_ae2e091fefc4c767117727bd5aba4d99e}{os\+Status}} os\+Thread\+Suspend (\begin{DoxyParamCaption}\item[{\mbox{\hyperlink{cmsis__os_8h_a217fdd2811440d39a6e8c868a0b8ec82}{os\+Thread\+Id}}}]{thread\+\_\+id}{}\end{DoxyParamCaption})}

Suspend execution of a thread. 

\begin{DoxyParams}{Paramètres}
{\em thread\+\_\+id} & thread ID obtained by \doxylink{cmsis__os_8c_ac59b5713cb083702dce759c73fd90dff}{os\+Thread\+Create} or \doxylink{cmsis__os_8c_ab1df2a28925862ef8f9cf4e1c995c5a7}{os\+Thread\+Get\+Id}. \\
\hline
\end{DoxyParams}

\begin{DoxyRetVals}{Valeurs retournées}
{\em status} & code that indicates the execution status of the function. \\
\hline
\end{DoxyRetVals}
\Hypertarget{cmsis__os_8c_a56a2ad8a2fb63a7fdad28d2e9411c3a1}\index{cmsis\_os.c@{cmsis\_os.c}!osThreadSuspendAll@{osThreadSuspendAll}}
\index{osThreadSuspendAll@{osThreadSuspendAll}!cmsis\_os.c@{cmsis\_os.c}}
\doxysubsubsection{\texorpdfstring{osThreadSuspendAll()}{osThreadSuspendAll()}}
{\footnotesize\ttfamily \label{cmsis__os_8c_a56a2ad8a2fb63a7fdad28d2e9411c3a1} 
\mbox{\hyperlink{cmsis__os_8h_ae2e091fefc4c767117727bd5aba4d99e}{os\+Status}} os\+Thread\+Suspend\+All (\begin{DoxyParamCaption}\item[{void}]{}{}\end{DoxyParamCaption})}

Suspend execution of a all active threads. 

\begin{DoxyRetVals}{Valeurs retournées}
{\em status} & code that indicates the execution status of the function. \\
\hline
\end{DoxyRetVals}
\Hypertarget{cmsis__os_8c_aea135bb90eb853eff39e0800b91bbeab}\index{cmsis\_os.c@{cmsis\_os.c}!osThreadTerminate@{osThreadTerminate}}
\index{osThreadTerminate@{osThreadTerminate}!cmsis\_os.c@{cmsis\_os.c}}
\doxysubsubsection{\texorpdfstring{osThreadTerminate()}{osThreadTerminate()}}
{\footnotesize\ttfamily \label{cmsis__os_8c_aea135bb90eb853eff39e0800b91bbeab} 
\mbox{\hyperlink{cmsis__os_8h_ae2e091fefc4c767117727bd5aba4d99e}{os\+Status}} os\+Thread\+Terminate (\begin{DoxyParamCaption}\item[{\mbox{\hyperlink{cmsis__os_8h_a217fdd2811440d39a6e8c868a0b8ec82}{os\+Thread\+Id}}}]{thread\+\_\+id}{}\end{DoxyParamCaption})}

Terminate execution of a thread and remove it from Active Threads. 

\begin{DoxyParams}{Paramètres}
{\em thread\+\_\+id} & thread ID obtained by \doxylink{cmsis__os_8c_ac59b5713cb083702dce759c73fd90dff}{os\+Thread\+Create} or \doxylink{cmsis__os_8c_ab1df2a28925862ef8f9cf4e1c995c5a7}{os\+Thread\+Get\+Id}. \\
\hline
\end{DoxyParams}

\begin{DoxyRetVals}{Valeurs retournées}
{\em status} & code that indicates the execution status of the function. \\
\hline
\end{DoxyRetVals}
\begin{DoxyNote}{Note}
MUST REMAIN UNCHANGED\+: {\bfseries{os\+Thread\+Terminate}} shall be consistent in every CMSIS-\/\+RTOS. 
\end{DoxyNote}
\Hypertarget{cmsis__os_8c_af13a667493c5d629a90c13e113b99233}\index{cmsis\_os.c@{cmsis\_os.c}!osThreadYield@{osThreadYield}}
\index{osThreadYield@{osThreadYield}!cmsis\_os.c@{cmsis\_os.c}}
\doxysubsubsection{\texorpdfstring{osThreadYield()}{osThreadYield()}}
{\footnotesize\ttfamily \label{cmsis__os_8c_af13a667493c5d629a90c13e113b99233} 
\mbox{\hyperlink{cmsis__os_8h_ae2e091fefc4c767117727bd5aba4d99e}{os\+Status}} os\+Thread\+Yield (\begin{DoxyParamCaption}\item[{void}]{}{}\end{DoxyParamCaption})}

Pass control to next thread that is in state {\bfseries{READY}}. 

\begin{DoxyRetVals}{Valeurs retournées}
{\em status} & code that indicates the execution status of the function. \\
\hline
\end{DoxyRetVals}
\begin{DoxyNote}{Note}
MUST REMAIN UNCHANGED\+: {\bfseries{os\+Thread\+Yield}} shall be consistent in every CMSIS-\/\+RTOS. 
\end{DoxyNote}
\Hypertarget{cmsis__os_8c_aedd312bfdca04e0b8162b666e09a1ae6}\index{cmsis\_os.c@{cmsis\_os.c}!osTimerCreate@{osTimerCreate}}
\index{osTimerCreate@{osTimerCreate}!cmsis\_os.c@{cmsis\_os.c}}
\doxysubsubsection{\texorpdfstring{osTimerCreate()}{osTimerCreate()}}
{\footnotesize\ttfamily \label{cmsis__os_8c_aedd312bfdca04e0b8162b666e09a1ae6} 
\mbox{\hyperlink{cmsis__os_8h_a6416f2f47941043a63be8453cecce5be}{os\+Timer\+Id}} os\+Timer\+Create (\begin{DoxyParamCaption}\item[{const \mbox{\hyperlink{cmsis__os_8h_a2144eb7d94a485f516bf0b09078f883a}{os\+Timer\+Def\+\_\+t}} \texorpdfstring{$\ast$}{*}}]{timer\+\_\+def}{, }\item[{\mbox{\hyperlink{cmsis__os_8h_adac860eb9e1b4b0619271e6595ed83d9}{os\+\_\+timer\+\_\+type}}}]{type}{, }\item[{void \texorpdfstring{$\ast$}{*}}]{argument}{}\end{DoxyParamCaption})}

Create a timer. 

\begin{DoxyParams}{Paramètres}
{\em timer\+\_\+def} & timer object referenced with \doxylink{cmsis__os_8h_a1b8d670eaf964b2910fa06885e650678}{os\+Timer}. \\
\hline
{\em type} & os\+Timer\+Once for one-\/shot or os\+Timer\+Periodic for periodic behavior. \\
\hline
{\em argument} & argument to the timer call back function. \\
\hline
\end{DoxyParams}

\begin{DoxyRetVals}{Valeurs retournées}
{\em timer} & ID for reference by other functions or NULL in case of error. \\
\hline
\end{DoxyRetVals}
\begin{DoxyNote}{Note}
MUST REMAIN UNCHANGED\+: {\bfseries{os\+Timer\+Create}} shall be consistent in every CMSIS-\/\+RTOS. 
\end{DoxyNote}
\Hypertarget{cmsis__os_8c_a746b8043d906849bd65e3900fcb483cf}\index{cmsis\_os.c@{cmsis\_os.c}!osTimerDelete@{osTimerDelete}}
\index{osTimerDelete@{osTimerDelete}!cmsis\_os.c@{cmsis\_os.c}}
\doxysubsubsection{\texorpdfstring{osTimerDelete()}{osTimerDelete()}}
{\footnotesize\ttfamily \label{cmsis__os_8c_a746b8043d906849bd65e3900fcb483cf} 
\mbox{\hyperlink{cmsis__os_8h_ae2e091fefc4c767117727bd5aba4d99e}{os\+Status}} os\+Timer\+Delete (\begin{DoxyParamCaption}\item[{\mbox{\hyperlink{cmsis__os_8h_a6416f2f47941043a63be8453cecce5be}{os\+Timer\+Id}}}]{timer\+\_\+id}{}\end{DoxyParamCaption})}

Delete a timer. 

\begin{DoxyParams}{Paramètres}
{\em timer\+\_\+id} & timer ID obtained by \doxylink{cmsis__os_8c_aedd312bfdca04e0b8162b666e09a1ae6}{os\+Timer\+Create} \\
\hline
\end{DoxyParams}

\begin{DoxyRetVals}{Valeurs retournées}
{\em status} & code that indicates the execution status of the function. \\
\hline
\end{DoxyRetVals}
\begin{DoxyNote}{Note}
MUST REMAIN UNCHANGED\+: {\bfseries{os\+Timer\+Delete}} shall be consistent in every CMSIS-\/\+RTOS. 
\end{DoxyNote}
\Hypertarget{cmsis__os_8c_a27a797a401b068e2644d1125f22a07ca}\index{cmsis\_os.c@{cmsis\_os.c}!osTimerStart@{osTimerStart}}
\index{osTimerStart@{osTimerStart}!cmsis\_os.c@{cmsis\_os.c}}
\doxysubsubsection{\texorpdfstring{osTimerStart()}{osTimerStart()}}
{\footnotesize\ttfamily \label{cmsis__os_8c_a27a797a401b068e2644d1125f22a07ca} 
\mbox{\hyperlink{cmsis__os_8h_ae2e091fefc4c767117727bd5aba4d99e}{os\+Status}} os\+Timer\+Start (\begin{DoxyParamCaption}\item[{\mbox{\hyperlink{cmsis__os_8h_a6416f2f47941043a63be8453cecce5be}{os\+Timer\+Id}}}]{timer\+\_\+id}{, }\item[{uint32\+\_\+t}]{millisec}{}\end{DoxyParamCaption})}

Start or restart a timer. 

\begin{DoxyParams}{Paramètres}
{\em timer\+\_\+id} & timer ID obtained by \doxylink{cmsis__os_8c_aedd312bfdca04e0b8162b666e09a1ae6}{os\+Timer\+Create}. \\
\hline
{\em millisec} & time delay value of the timer. \\
\hline
\end{DoxyParams}

\begin{DoxyRetVals}{Valeurs retournées}
{\em status} & code that indicates the execution status of the function \\
\hline
\end{DoxyRetVals}
\begin{DoxyNote}{Note}
MUST REMAIN UNCHANGED\+: {\bfseries{os\+Timer\+Start}} shall be consistent in every CMSIS-\/\+RTOS. 
\end{DoxyNote}
\Hypertarget{cmsis__os_8c_a58f36b121a812936435cacc6e1e0e091}\index{cmsis\_os.c@{cmsis\_os.c}!osTimerStop@{osTimerStop}}
\index{osTimerStop@{osTimerStop}!cmsis\_os.c@{cmsis\_os.c}}
\doxysubsubsection{\texorpdfstring{osTimerStop()}{osTimerStop()}}
{\footnotesize\ttfamily \label{cmsis__os_8c_a58f36b121a812936435cacc6e1e0e091} 
\mbox{\hyperlink{cmsis__os_8h_ae2e091fefc4c767117727bd5aba4d99e}{os\+Status}} os\+Timer\+Stop (\begin{DoxyParamCaption}\item[{\mbox{\hyperlink{cmsis__os_8h_a6416f2f47941043a63be8453cecce5be}{os\+Timer\+Id}}}]{timer\+\_\+id}{}\end{DoxyParamCaption})}

Stop a timer. 

\begin{DoxyParams}{Paramètres}
{\em timer\+\_\+id} & timer ID obtained by \doxylink{cmsis__os_8c_aedd312bfdca04e0b8162b666e09a1ae6}{os\+Timer\+Create} \\
\hline
\end{DoxyParams}

\begin{DoxyRetVals}{Valeurs retournées}
{\em status} & code that indicates the execution status of the function. \\
\hline
\end{DoxyRetVals}
\begin{DoxyNote}{Note}
MUST REMAIN UNCHANGED\+: {\bfseries{os\+Timer\+Stop}} shall be consistent in every CMSIS-\/\+RTOS. 
\end{DoxyNote}
\Hypertarget{cmsis__os_8c_a78100b2d36913d0b45565be8975e5de8}\index{cmsis\_os.c@{cmsis\_os.c}!xPortSysTickHandler@{xPortSysTickHandler}}
\index{xPortSysTickHandler@{xPortSysTickHandler}!cmsis\_os.c@{cmsis\_os.c}}
\doxysubsubsection{\texorpdfstring{xPortSysTickHandler()}{xPortSysTickHandler()}}
{\footnotesize\ttfamily \label{cmsis__os_8c_a78100b2d36913d0b45565be8975e5de8} 
void x\+Port\+Sys\+Tick\+Handler (\begin{DoxyParamCaption}\item[{void}]{}{}\end{DoxyParamCaption})\hspace{0.3cm}{\ttfamily [extern]}}

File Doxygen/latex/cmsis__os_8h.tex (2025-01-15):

\doxysection{Référence du fichier cmsis\+\_\+os.\+h}
\hypertarget{cmsis__os_8h}{}\label{cmsis__os_8h}\index{cmsis\_os.h@{cmsis\_os.h}}
{\ttfamily \#include "{}Free\+RTOS.\+h"{}}\newline
{\ttfamily \#include "{}task.\+h"{}}\newline
{\ttfamily \#include "{}timers.\+h"{}}\newline
{\ttfamily \#include "{}queue.\+h"{}}\newline
{\ttfamily \#include "{}semphr.\+h"{}}\newline
{\ttfamily \#include "{}event\+\_\+groups.\+h"{}}\newline
\doxysubsubsection*{Structures de données}
\begin{DoxyCompactItemize}
\item 
struct \mbox{\hyperlink{structos__thread__def}{os\+\_\+thread\+\_\+def}}
\item 
struct \mbox{\hyperlink{structos__timer__def}{os\+\_\+timer\+\_\+def}}
\item 
struct \mbox{\hyperlink{structos__mutex__def}{os\+\_\+mutex\+\_\+def}}
\item 
struct \mbox{\hyperlink{structos__semaphore__def}{os\+\_\+semaphore\+\_\+def}}
\item 
struct \mbox{\hyperlink{structos__pool__def}{os\+\_\+pool\+\_\+def}}
\item 
struct \mbox{\hyperlink{structos__message_q__def}{os\+\_\+message\+Q\+\_\+def}}
\item 
struct \mbox{\hyperlink{structos__mail_q__def}{os\+\_\+mail\+Q\+\_\+def}}
\item 
struct \mbox{\hyperlink{structos_event}{os\+Event}}
\end{DoxyCompactItemize}
\doxysubsubsection*{Macros}
\begin{DoxyCompactItemize}
\item 
\#define \mbox{\hyperlink{cmsis__os_8h_a702196bacccbb978620c736b209387f1}{os\+CMSIS}}~0x10002
\begin{DoxyCompactList}\small\item\em API version (main \mbox{[}31\+:16\mbox{]} .sub \mbox{[}15\+:0\mbox{]}) \end{DoxyCompactList}\item 
\#define \mbox{\hyperlink{cmsis__os_8h_ab78dce646fabec479c5f34bc5175b7de}{os\+CMSIS\+\_\+\+KERNEL}}~0x10000
\begin{DoxyCompactList}\small\item\em RTOS identification and version (main \mbox{[}31\+:16\mbox{]} .sub \mbox{[}15\+:0\mbox{]}) \end{DoxyCompactList}\item 
\#define \mbox{\hyperlink{cmsis__os_8h_a47cf03658f01cdffca688e9096b58289}{os\+Kernel\+System\+Id}}~"{}KERNEL V1.\+00"{}
\begin{DoxyCompactList}\small\item\em RTOS identification string. \end{DoxyCompactList}\item 
\#define \mbox{\hyperlink{cmsis__os_8h_a22f7d235bc9f783933bd5a981fd79696}{os\+Feature\+\_\+\+Main\+Thread}}~1
\begin{DoxyCompactList}\small\item\em main thread 1=main can be thread, 0=not available \end{DoxyCompactList}\item 
\#define \mbox{\hyperlink{cmsis__os_8h_add84b683001de327894851b428587caa}{os\+Feature\+\_\+\+Pool}}~1
\begin{DoxyCompactList}\small\item\em Memory Pools\+: 1=available, 0=not available. \end{DoxyCompactList}\item 
\#define \mbox{\hyperlink{cmsis__os_8h_aceb2e0071ce160d153047f2eac1aca8e}{os\+Feature\+\_\+\+MailQ}}~1
\begin{DoxyCompactList}\small\item\em Mail Queues\+: 1=available, 0=not available. \end{DoxyCompactList}\item 
\#define \mbox{\hyperlink{cmsis__os_8h_a479a6561f859e3d4818e25708593d203}{os\+Feature\+\_\+\+MessageQ}}~1
\begin{DoxyCompactList}\small\item\em Message Queues\+: 1=available, 0=not available. \end{DoxyCompactList}\item 
\#define \mbox{\hyperlink{cmsis__os_8h_a01edde265710d883b6e237d34a6ef4a6}{os\+Feature\+\_\+\+Signals}}~8
\begin{DoxyCompactList}\small\item\em maximum number of Signal Flags available per thread \end{DoxyCompactList}\item 
\#define \mbox{\hyperlink{cmsis__os_8h_a7da4c7bfb340779c9fc7b321f5ab3e3a}{os\+Feature\+\_\+\+Semaphore}}~1
\begin{DoxyCompactList}\small\item\em os\+Feature\+\_\+\+Semaphore function\+: 1=available, 0=not available \end{DoxyCompactList}\item 
\#define \mbox{\hyperlink{cmsis__os_8h_a6c97d38879ae86491628f6e647639bad}{os\+Feature\+\_\+\+Wait}}~0
\begin{DoxyCompactList}\small\item\em os\+Wait function\+: 1=available, 0=not available \end{DoxyCompactList}\item 
\#define \mbox{\hyperlink{cmsis__os_8h_ae554ec16c23c5b7d65affade2a351891}{os\+Feature\+\_\+\+Sys\+Tick}}~1
\begin{DoxyCompactList}\small\item\em os\+Kernel\+Sys\+Tick functions\+: 1=available, 0=not available \end{DoxyCompactList}\item 
\#define \mbox{\hyperlink{cmsis__os_8h_a9eb9a7a797a42e4b55eb171ecc609ddb}{os\+Wait\+Forever}}~0x\+FFFFFFFF
\begin{DoxyCompactList}\small\item\em wait forever timeout value \end{DoxyCompactList}\item 
\#define \mbox{\hyperlink{cmsis__os_8h_a9e0954d52722673e2031233a2ab99960}{os\+Kernel\+Sys\+Tick\+Frequency}}~(\mbox{\hyperlink{_free_r_t_o_s_config_8h_a2f0258dd1e3b877e5bc013be54c2db6a}{config\+TICK\+\_\+\+RATE\+\_\+\+HZ}})
\item 
\#define \mbox{\hyperlink{cmsis__os_8h_ae12c190af42d7310d8006d64f4ed5a88}{os\+Kernel\+Sys\+Tick\+Micro\+Sec}}(microsec)
\item 
\#define \mbox{\hyperlink{cmsis__os_8h_a1537e80813785bebbc3cbab3226eb04f}{os\+Thread\+Def}}(name,  thread,  priority,  instances,  stacksz)
\item 
\#define \mbox{\hyperlink{cmsis__os_8h_af0c7c6b5e09f8be198312144b5c9e453}{os\+Thread}}(name)
\item 
\#define \mbox{\hyperlink{cmsis__os_8h_a1c720627e08d1cc1afcad44e799ed492}{os\+Timer\+Def}}(name,  function)
\item 
\#define \mbox{\hyperlink{cmsis__os_8h_a1b8d670eaf964b2910fa06885e650678}{os\+Timer}}(name)
\item 
\#define \mbox{\hyperlink{cmsis__os_8h_a9b522438489d7c402c95332b58bc94f3}{os\+Mutex\+Def}}(name)
\item 
\#define \mbox{\hyperlink{cmsis__os_8h_a1122a86faa64b4a0880c76cf68d0c934}{os\+Mutex}}(name)
\item 
\#define \mbox{\hyperlink{cmsis__os_8h_a9e66fe361749071e5ab87826c43c2f1b}{os\+Semaphore\+Def}}(name)
\item 
\#define \mbox{\hyperlink{cmsis__os_8h_a03761ee8d2c3cd4544e18364ab301dac}{os\+Semaphore}}(name)
\item 
\#define \mbox{\hyperlink{cmsis__os_8h_a87b471d4fe2d5dbd0040708edd52771b}{os\+Pool\+Def}}(name,  no,  type)
\begin{DoxyCompactList}\small\item\em Define a Memory Pool. \end{DoxyCompactList}\item 
\#define \mbox{\hyperlink{cmsis__os_8h_a5f0b204a82327533d420210125c90697}{os\+Pool}}(name)
\begin{DoxyCompactList}\small\item\em Access a Memory Pool definition. \end{DoxyCompactList}\item 
\#define \mbox{\hyperlink{cmsis__os_8h_ac9a6a6276c12609793e7701afcc82326}{os\+Message\+QDef}}(name,  queue\+\_\+sz,  type)
\begin{DoxyCompactList}\small\item\em Create a Message Queue Definition. \end{DoxyCompactList}\item 
\#define \mbox{\hyperlink{cmsis__os_8h_a2d446a0b4bb90bf05d6f92eedeaabc97}{os\+MessageQ}}(name)
\begin{DoxyCompactList}\small\item\em Access a Message Queue Definition. \end{DoxyCompactList}\item 
\#define \mbox{\hyperlink{cmsis__os_8h_a58d712b16c0c6668059f509386d1e55b}{os\+Mail\+QDef}}(name,  queue\+\_\+sz,  type)
\begin{DoxyCompactList}\small\item\em Create a Mail Queue Definition. \end{DoxyCompactList}\item 
\#define \mbox{\hyperlink{cmsis__os_8h_ad2deeb66d51ade54e63d8f87ff2ec9d2}{os\+MailQ}}(name)
\begin{DoxyCompactList}\small\item\em Access a Mail Queue Definition. \end{DoxyCompactList}\end{DoxyCompactItemize}
\doxysubsubsection*{Définitions de type}
\begin{DoxyCompactItemize}
\item 
typedef void(\texorpdfstring{$\ast$}{*} \mbox{\hyperlink{cmsis__os_8h_a3a96994ab8318050b476d72d890ce765}{os\+\_\+pthread}}) (void const \texorpdfstring{$\ast$}{*}argument)
\item 
typedef void(\texorpdfstring{$\ast$}{*} \mbox{\hyperlink{cmsis__os_8h_a7904cad2180c6b3a0ac112fe8ff273e7}{os\+\_\+ptimer}}) (void const \texorpdfstring{$\ast$}{*}argument)
\item 
typedef \mbox{\hyperlink{task_8h_a25b35e6e19ecf894173e7ff95edb96ef}{Task\+Handle\+\_\+t}} \mbox{\hyperlink{cmsis__os_8h_a217fdd2811440d39a6e8c868a0b8ec82}{os\+Thread\+Id}}
\item 
typedef \mbox{\hyperlink{timers_8h_ae2aa96927b4806e5dcfd264ba7bc8bf6}{Timer\+Handle\+\_\+t}} \mbox{\hyperlink{cmsis__os_8h_a6416f2f47941043a63be8453cecce5be}{os\+Timer\+Id}}
\item 
typedef \mbox{\hyperlink{semphr_8h_ad88c6df4a04beedeac782918c8a332f5}{Semaphore\+Handle\+\_\+t}} \mbox{\hyperlink{cmsis__os_8h_abba580e11219b5ec867b5b26ac0b87f4}{os\+Mutex\+Id}}
\item 
typedef \mbox{\hyperlink{semphr_8h_ad88c6df4a04beedeac782918c8a332f5}{Semaphore\+Handle\+\_\+t}} \mbox{\hyperlink{cmsis__os_8h_a954e9c06583b05ae736d07e4e40097d5}{os\+Semaphore\+Id}}
\item 
typedef struct \mbox{\hyperlink{structos__pool__cb}{os\+\_\+pool\+\_\+cb}} \texorpdfstring{$\ast$}{*} \mbox{\hyperlink{cmsis__os_8h_a08d2e20fd9bbd96220fe068d420f3686}{os\+Pool\+Id}}
\item 
typedef \mbox{\hyperlink{queue_8h_a57349603001f8ddf51c888c49e2804d7}{Queue\+Handle\+\_\+t}} \mbox{\hyperlink{cmsis__os_8h_a8c191fd2b1369c8942873496a186a022}{os\+Message\+QId}}
\item 
typedef struct \mbox{\hyperlink{structos__mail_q__cb}{os\+\_\+mail\+Q\+\_\+cb}} \texorpdfstring{$\ast$}{*} \mbox{\hyperlink{cmsis__os_8h_a1dac049fb7725a8af8b26c71cbb373b5}{os\+Mail\+QId}}
\item 
typedef struct \mbox{\hyperlink{structos__thread__def}{os\+\_\+thread\+\_\+def}} \mbox{\hyperlink{cmsis__os_8h_a92f46bd508dcc685135882e2cf37ac8c}{os\+Thread\+Def\+\_\+t}}
\item 
typedef struct \mbox{\hyperlink{structos__timer__def}{os\+\_\+timer\+\_\+def}} \mbox{\hyperlink{cmsis__os_8h_a2144eb7d94a485f516bf0b09078f883a}{os\+Timer\+Def\+\_\+t}}
\item 
typedef struct \mbox{\hyperlink{structos__mutex__def}{os\+\_\+mutex\+\_\+def}} \mbox{\hyperlink{cmsis__os_8h_ac2907bdcc057de650ea61777a0e92d11}{os\+Mutex\+Def\+\_\+t}}
\item 
typedef struct \mbox{\hyperlink{structos__semaphore__def}{os\+\_\+semaphore\+\_\+def}} \mbox{\hyperlink{cmsis__os_8h_acf4486afa668a4499003e1a750eb8ab1}{os\+Semaphore\+Def\+\_\+t}}
\item 
typedef struct \mbox{\hyperlink{structos__pool__def}{os\+\_\+pool\+\_\+def}} \mbox{\hyperlink{cmsis__os_8h_ac47b811c41974c0bb74521a50c7983b7}{os\+Pool\+Def\+\_\+t}}
\item 
typedef struct \mbox{\hyperlink{structos__message_q__def}{os\+\_\+message\+Q\+\_\+def}} \mbox{\hyperlink{cmsis__os_8h_a552ffc97e37e403acff6a59793ad26eb}{os\+Message\+QDef\+\_\+t}}
\item 
typedef struct \mbox{\hyperlink{structos__mail_q__def}{os\+\_\+mail\+Q\+\_\+def}} \mbox{\hyperlink{cmsis__os_8h_ab6d3ddc7d8cea9901544118bed1a3d1c}{os\+Mail\+QDef\+\_\+t}}
\end{DoxyCompactItemize}
\doxysubsubsection*{Énumérations}
\begin{DoxyCompactItemize}
\item 
enum \mbox{\hyperlink{cmsis__os_8h_a7f2b42f1983b9107775ec2a1c69a849a}{os\+Priority}} \{ \newline
\mbox{\hyperlink{cmsis__os_8h_a7f2b42f1983b9107775ec2a1c69a849aa549e79a43ff4f8b2b31afb613f5caa81}{os\+Priority\+Idle}} = -\/3
, \mbox{\hyperlink{cmsis__os_8h_a7f2b42f1983b9107775ec2a1c69a849aa61cb822239ac8f66dfbdc7291598a3d4}{os\+Priority\+Low}} = -\/2
, \mbox{\hyperlink{cmsis__os_8h_a7f2b42f1983b9107775ec2a1c69a849aa193b650117c209b4a203954542bcc3e6}{os\+Priority\+Below\+Normal}} = -\/1
, \mbox{\hyperlink{cmsis__os_8h_a7f2b42f1983b9107775ec2a1c69a849aa45a2895ad30c79fb97de18cac7cc19f1}{os\+Priority\+Normal}} = 0
, \newline
\mbox{\hyperlink{cmsis__os_8h_a7f2b42f1983b9107775ec2a1c69a849aa17b36cd9cd38652c2bc6d4803990674b}{os\+Priority\+Above\+Normal}} = +1
, \mbox{\hyperlink{cmsis__os_8h_a7f2b42f1983b9107775ec2a1c69a849aa914433934143a9ba767e59577c56e6c2}{os\+Priority\+High}} = +2
, \mbox{\hyperlink{cmsis__os_8h_a7f2b42f1983b9107775ec2a1c69a849aa1485dec3702434a1ec3cb74c7a17a4af}{os\+Priority\+Realtime}} = +3
, \mbox{\hyperlink{cmsis__os_8h_a7f2b42f1983b9107775ec2a1c69a849aae35f5e2f9c64ad346822521b643bdea4}{os\+Priority\+Error}} = 0x84
 \}
\item 
enum \mbox{\hyperlink{cmsis__os_8h_ae2e091fefc4c767117727bd5aba4d99e}{os\+Status}} \{ \newline
\mbox{\hyperlink{cmsis__os_8h_ae2e091fefc4c767117727bd5aba4d99ea9e1c9e2550bb4de8969a935acffc968f}{os\+OK}} = 0
, \mbox{\hyperlink{cmsis__os_8h_ae2e091fefc4c767117727bd5aba4d99ea5df7e9643aa8a2f5f3a6f6ec59758518}{os\+Event\+Signal}} = 0x08
, \mbox{\hyperlink{cmsis__os_8h_ae2e091fefc4c767117727bd5aba4d99ead604f3673359dd4ac643b16dc5a2c342}{os\+Event\+Message}} = 0x10
, \mbox{\hyperlink{cmsis__os_8h_ae2e091fefc4c767117727bd5aba4d99ea15b12e42b42b53f35fb8a2724ad02926}{os\+Event\+Mail}} = 0x20
, \newline
\mbox{\hyperlink{cmsis__os_8h_ae2e091fefc4c767117727bd5aba4d99ea78f477732375c0e1fca814e369618177}{os\+Event\+Timeout}} = 0x40
, \mbox{\hyperlink{cmsis__os_8h_ae2e091fefc4c767117727bd5aba4d99eac24adca6a5d072c9f01c32178ba0d109}{os\+Error\+Parameter}} = 0x80
, \mbox{\hyperlink{cmsis__os_8h_ae2e091fefc4c767117727bd5aba4d99ea8fc5801e8b0482bdf22ad63a77f0155d}{os\+Error\+Resource}} = 0x81
, \mbox{\hyperlink{cmsis__os_8h_ae2e091fefc4c767117727bd5aba4d99ea314d24a49003f09459035db0dd7c9467}{os\+Error\+Timeout\+Resource}} = 0x\+C1
, \newline
\mbox{\hyperlink{cmsis__os_8h_ae2e091fefc4c767117727bd5aba4d99ea21635bdc492d3094fe83027fa4a30e2f}{os\+Error\+ISR}} = 0x82
, \mbox{\hyperlink{cmsis__os_8h_ae2e091fefc4c767117727bd5aba4d99eaf6552310a817452aedfcd453f2805d65}{os\+Error\+ISRRecursive}} = 0x83
, \mbox{\hyperlink{cmsis__os_8h_ae2e091fefc4c767117727bd5aba4d99eab7dda0ef504817659334cbfd650ae56f}{os\+Error\+Priority}} = 0x84
, \mbox{\hyperlink{cmsis__os_8h_ae2e091fefc4c767117727bd5aba4d99eaf1fac0240218e51eb30a13da2f8aae81}{os\+Error\+No\+Memory}} = 0x85
, \newline
\mbox{\hyperlink{cmsis__os_8h_ae2e091fefc4c767117727bd5aba4d99ea4672c8a0c0f6bb1d7981da4602e8e9ee}{os\+Error\+Value}} = 0x86
, \mbox{\hyperlink{cmsis__os_8h_ae2e091fefc4c767117727bd5aba4d99ea5fde24ff588ec5ab9cb8314bade26fbc}{os\+Error\+OS}} = 0x\+FF
, \mbox{\hyperlink{cmsis__os_8h_ae2e091fefc4c767117727bd5aba4d99eac7a77f5fe18a15a357790c36a4aca1b1}{os\+\_\+status\+\_\+reserved}} = 0x7\+FFFFFFF
 \}
\item 
enum \mbox{\hyperlink{cmsis__os_8h_adac860eb9e1b4b0619271e6595ed83d9}{os\+\_\+timer\+\_\+type}} \{ \mbox{\hyperlink{cmsis__os_8h_adac860eb9e1b4b0619271e6595ed83d9ad21712f8df5f97069c82dc9eec37b951}{os\+Timer\+Once}} = 0
, \mbox{\hyperlink{cmsis__os_8h_adac860eb9e1b4b0619271e6595ed83d9ab9c91f9699162edb09bb7c90c11c8788}{os\+Timer\+Periodic}} = 1
 \}
\end{DoxyCompactItemize}
\doxysubsubsection*{Fonctions}
\begin{DoxyCompactItemize}
\item 
\mbox{\hyperlink{cmsis__os_8h_ae2e091fefc4c767117727bd5aba4d99e}{os\+Status}} \mbox{\hyperlink{cmsis__os_8h_a53d078a801022e202e8115c083ece68e}{os\+Kernel\+Initialize}} (void)
\item 
\mbox{\hyperlink{cmsis__os_8h_ae2e091fefc4c767117727bd5aba4d99e}{os\+Status}} \mbox{\hyperlink{cmsis__os_8h_aab668ffd2ea76bb0a77ab0ab385eaef2}{os\+Kernel\+Start}} (void)
\begin{DoxyCompactList}\small\item\em Start the RTOS Kernel with executing the specified thread. \end{DoxyCompactList}\item 
int32\+\_\+t \mbox{\hyperlink{cmsis__os_8h_a3b571de44cd3094c643247a7397f86b5}{os\+Kernel\+Running}} (void)
\begin{DoxyCompactList}\small\item\em Check if the RTOS kernel is already started. \end{DoxyCompactList}\item 
uint32\+\_\+t \mbox{\hyperlink{cmsis__os_8h_ad0262e4688e95d1e9038afd9bcc16001}{os\+Kernel\+Sys\+Tick}} (void)
\begin{DoxyCompactList}\small\item\em Get the value of the Kernel Sys\+Tick timer. \end{DoxyCompactList}\item 
\mbox{\hyperlink{cmsis__os_8h_a217fdd2811440d39a6e8c868a0b8ec82}{os\+Thread\+Id}} \mbox{\hyperlink{cmsis__os_8h_ac59b5713cb083702dce759c73fd90dff}{os\+Thread\+Create}} (const \mbox{\hyperlink{cmsis__os_8h_a92f46bd508dcc685135882e2cf37ac8c}{os\+Thread\+Def\+\_\+t}} \texorpdfstring{$\ast$}{*}thread\+\_\+def, void \texorpdfstring{$\ast$}{*}argument)
\begin{DoxyCompactList}\small\item\em Create a thread and add it to Active Threads and set it to state READY. \end{DoxyCompactList}\item 
\mbox{\hyperlink{cmsis__os_8h_a217fdd2811440d39a6e8c868a0b8ec82}{os\+Thread\+Id}} \mbox{\hyperlink{cmsis__os_8h_ab1df2a28925862ef8f9cf4e1c995c5a7}{os\+Thread\+Get\+Id}} (void)
\begin{DoxyCompactList}\small\item\em Return the thread ID of the current running thread. \end{DoxyCompactList}\item 
\mbox{\hyperlink{cmsis__os_8h_ae2e091fefc4c767117727bd5aba4d99e}{os\+Status}} \mbox{\hyperlink{cmsis__os_8h_aea135bb90eb853eff39e0800b91bbeab}{os\+Thread\+Terminate}} (\mbox{\hyperlink{cmsis__os_8h_a217fdd2811440d39a6e8c868a0b8ec82}{os\+Thread\+Id}} thread\+\_\+id)
\begin{DoxyCompactList}\small\item\em Terminate execution of a thread and remove it from Active Threads. \end{DoxyCompactList}\item 
\mbox{\hyperlink{cmsis__os_8h_ae2e091fefc4c767117727bd5aba4d99e}{os\+Status}} \mbox{\hyperlink{cmsis__os_8h_af13a667493c5d629a90c13e113b99233}{os\+Thread\+Yield}} (void)
\begin{DoxyCompactList}\small\item\em Pass control to next thread that is in state {\bfseries{READY}}. \end{DoxyCompactList}\item 
\mbox{\hyperlink{cmsis__os_8h_ae2e091fefc4c767117727bd5aba4d99e}{os\+Status}} \mbox{\hyperlink{cmsis__os_8h_a0dfb90ccf1f6e4b54b9251b12d1cbc8b}{os\+Thread\+Set\+Priority}} (\mbox{\hyperlink{cmsis__os_8h_a217fdd2811440d39a6e8c868a0b8ec82}{os\+Thread\+Id}} thread\+\_\+id, \mbox{\hyperlink{cmsis__os_8h_a7f2b42f1983b9107775ec2a1c69a849a}{os\+Priority}} priority)
\begin{DoxyCompactList}\small\item\em Change priority of an active thread. \end{DoxyCompactList}\item 
\mbox{\hyperlink{cmsis__os_8h_a7f2b42f1983b9107775ec2a1c69a849a}{os\+Priority}} \mbox{\hyperlink{cmsis__os_8h_a4299d838978bc2aae5e4350754e6a4e9}{os\+Thread\+Get\+Priority}} (\mbox{\hyperlink{cmsis__os_8h_a217fdd2811440d39a6e8c868a0b8ec82}{os\+Thread\+Id}} thread\+\_\+id)
\begin{DoxyCompactList}\small\item\em Get current priority of an active thread. \end{DoxyCompactList}\item 
\mbox{\hyperlink{cmsis__os_8h_ae2e091fefc4c767117727bd5aba4d99e}{os\+Status}} \mbox{\hyperlink{cmsis__os_8h_a02e19d5e723bfb06ba9324d625162255}{os\+Delay}} (uint32\+\_\+t millisec)
\begin{DoxyCompactList}\small\item\em Wait for Timeout (Time Delay) \end{DoxyCompactList}\item
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

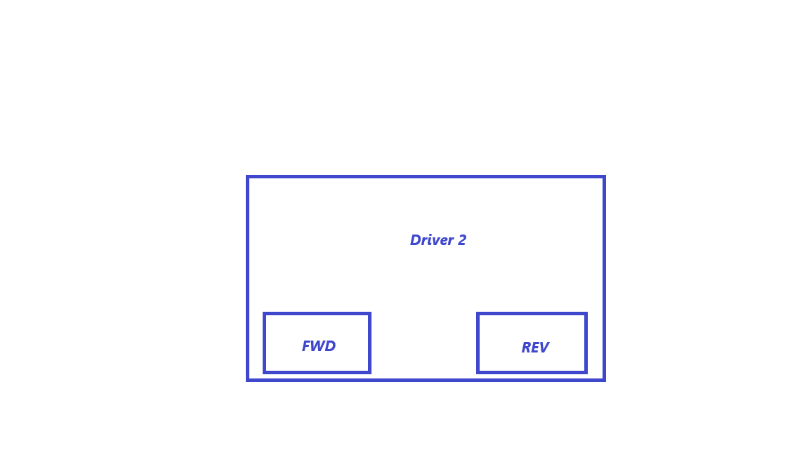
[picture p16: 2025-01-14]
annexes/assets/schemadriver_2-1736765823753-9.png

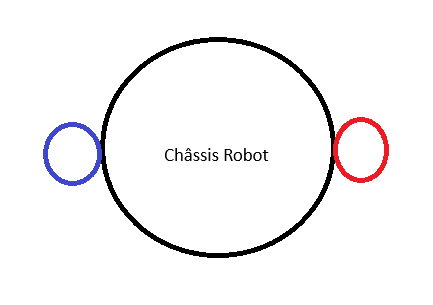
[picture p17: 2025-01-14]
annexes/assets/representatioon robot_capture.png

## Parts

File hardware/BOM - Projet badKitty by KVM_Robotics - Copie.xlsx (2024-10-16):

 | BOM Projet ESE_2024/2025
 | Création le : | 2024-09-11 |  | Prix de revient : |  | 128.99 €
Qté | Désignation | Marque | Réf. Fabricant | Fournisseur | Ref Fournisseur | Prix | Qte | Total € | Lien vers le shop | Datasheet
1 | Microcontrôleur STM32 | STM | STM32G431CBU6 |  | 3132404 | 6.10 € | 1 | 6.1
1 | Quartz 16 MHz | MULTICOMP PRO | MCSJK-7U-16.00-10-30-80-B-30 | Farnell (https://fr.farnell.com/stmicroelectronics/stm32g431cbu6/mcu-32-bits-170mhz-ufqfpn-48/dp/3132404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) | 2853935 | 0.22 € | 1 | 0.22
1 | STLink | STMICROELECTRONICS | ST-LINK/V2 | Farnell (https://fr.farnell.com/multicomp/mcsjk-7u-16-00-10-30-80-b-30/quartz-16mhz-10pf-3-2mm-x-2-5mm/dp/2853935) | 1892523 | 21.25 € | 1 | 21.25
1 | Connecteur SWD | HARWIN | M50-3600742 | farnell | 3226055 | 2.02 € | 1
2 | Driver moteur | Diode Inc. | ZXBM5210-SP-13 | FARNELL | 3946343 | 1.21 € | 2 | 2.42
4 | Moteurs | DfRobot | FIT0520 | Farnell (https://fr.farnell.com/diodes-inc/zxbm5210-sp-13/driver-de-moteur-40-105-c/dp/3946343) | 426-FIT0520 | 18.51 € | 4 | 74.04
1 | Accéléromètre | ANALOG DEVICES | ADXL343BCCZ-RL | MOUSER (https://www.mouser.fr/ProductDetail/DFRobot/FIT0520?qs=0lQeLiL1qyYDVHZEybM7cQ%3D%3D) | 4030101RL | 2.45 € | 1 | 2.45
1 | Régulateur 5V buck | MONOLITHIC POWER SYSTEMS (MPS) | MP1475S | Farnell (https://fr.farnell.com/analog-devices/adxl343bccz-rl7/acc-l-rom-tre-mems-num-axes-x/dp/4030101RL) | 3357926RL | 0.90 € | 1 | 0.901 |  | v
1 | Régulateur 3.3V LDO | ROHM | BU33SD5WG-TR | Farnell (https://fr.farnell.com/monolithic-power-systems-mps/mp1475sgj-p/conv-dc-dc-sync-buck-500khz-125/dp/3357926RL) | 3011248RL | 0.32 € | 1 | 0.321
1 | Batterie NIMH 7.2V 1.3Ah | RS PRO |  | Farnell (https://fr.farnell.com/rohm/bu33sd5wg-tr/ldo-fixe-3-3v-0-5a-40-a-105-c/dp/3011248RL) | 77-0377 | 21.29 € | 1 | 21.29
3 | LED |  |  | Robotshop (https://eu.robotshop.com/fr/products/ydlidar-x4pro-telemetre-2d-360-degres) |  |  | 3 | 0
1 | Connecteurs JST 2.54mm |  |  |  |  |  | 1 | 0
4 | Capteur bordure | VL53L1X PIM373 | 50mm to 1200mm | Gotronic |  | 13.95 | 4
 |  |  | VL53L1CXV0FY/1 | Gotronic (https://www.gotronic.fr/art-module-time-of-flight-vl53l1x-pim373-31588.htm)
 | Contrôleurs et régulateurs de courant et de puissance |  | NCS199A2RSQT2G | Farnell (https://fr.farnell.com/stmicroelectronics/vl53l1cxv0fy-1/capteur-proximite-drain-ouvert/dp/2851946)
 | LED et R C en 0603
 | Commutateur à Bascule | WURTH ELEKTRONIK | 472121020311 | Wurth |  | 5.82 | 1
 |  |  |  |  |  |  |  | 0

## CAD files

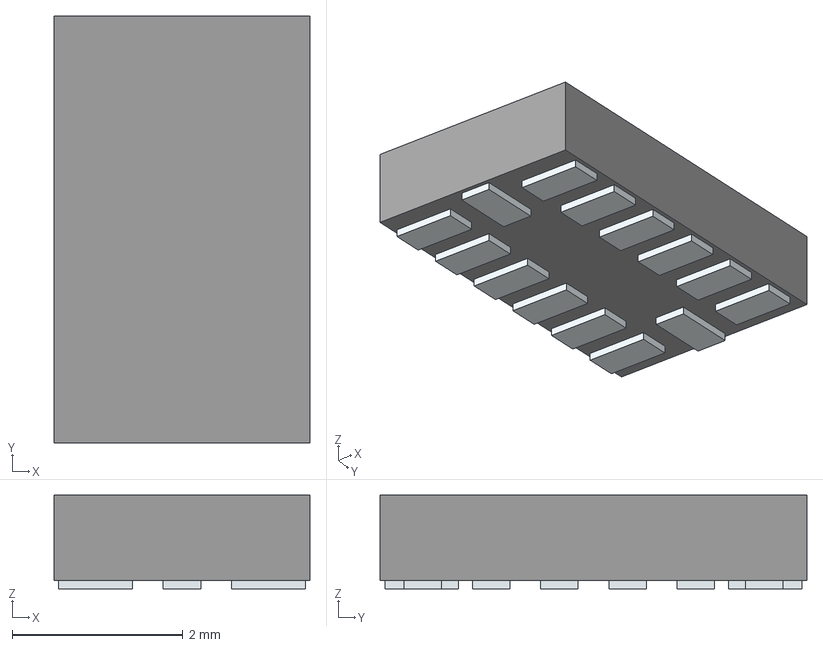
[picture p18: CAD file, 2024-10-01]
annexes/Documentation et datasheet/accelerometre/lib_adxl343/LIB_ADXL343BCCZ-RL/ADXL343BCCZ-RL/3D/ADXL343BCCZ-RL.stp
3.00 x 5.00 x 1.10 mm
Pins

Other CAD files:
annexes/Documentation et datasheet/accelerometre/lib_adxl343/LIB_ADXL343BCCZ-RL/ADXL343BCCZ-RL/Allegro/adxl343bcczrl.psm
annexes/Documentation et datasheet/accelerometre/lib_adxl343/LIB_ADXL343BCCZ-RL/ADXL343BCCZ-RL/DEHDL/adxl343bccz_rl/chips/chips.prt

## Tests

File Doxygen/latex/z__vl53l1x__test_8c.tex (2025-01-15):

\doxysection{Référence du fichier z\+\_\+vl53l1x\+\_\+test.\+c}
\hypertarget{z__vl53l1x__test_8c}{}\label{z__vl53l1x__test_8c}\index{z\_vl53l1x\_test.c@{z\_vl53l1x\_test.c}}
{\ttfamily \#include "{}vl53l1\+\_\+platform.\+h"{}}\newline
{\ttfamily \#include "{}main.\+h"{}}\newline
{\ttfamily \#include $<$math.\+h$>$}\newline
\doxysubsubsection*{Macros}
\begin{DoxyCompactItemize}
\item 
\#define \mbox{\hyperlink{z__vl53l1x__test_8c_a14df6345e8d840e0fa519bea201e4988}{DIM\+\_\+\+ARR}}~100
\end{DoxyCompactItemize}
\doxysubsubsection*{Fonctions}
\begin{DoxyCompactItemize}
\item 
void \mbox{\hyperlink{z__vl53l1x__test_8c_a03928b0a24d7f6c4719ee98a56c976fc}{VL53\+L1\+\_\+\+\_\+test}} ()
\end{DoxyCompactItemize}
\doxysubsubsection*{Variables}
\begin{DoxyCompactItemize}
\item 
uint16\+\_\+t \mbox{\hyperlink{z__vl53l1x__test_8c_a23eaf4ad03dd3ea6ccca26824b589ba1}{Distance}}
\item 
uint8\+\_\+t \mbox{\hyperlink{z__vl53l1x__test_8c_a850e4e5b2c2319b8168134e8397f69f0}{Range\+Status}}
\item 
uint16\+\_\+t \mbox{\hyperlink{z__vl53l1x__test_8c_ae0e1cab1c8d7bc781ec32fffee47dec4}{Signal\+Rate}}
\item 
uint16\+\_\+t \mbox{\hyperlink{z__vl53l1x__test_8c_ae9883292894ff2fabeea816fa0487cca}{Ambient\+Rate}}
\item 
uint16\+\_\+t \mbox{\hyperlink{z__vl53l1x__test_8c_abafcbdae32d0e890623e3c43e0b33afc}{Signal\+Per\+Spad}}
\item 
uint16\+\_\+t \mbox{\hyperlink{z__vl53l1x__test_8c_adaa0bc111b1e10351bb55566a2b5ce5b}{Ambient\+Per\+Spad}}
\item 
uint16\+\_\+t \mbox{\hyperlink{z__vl53l1x__test_8c_ac59106b4c004961b1bc62f7e05b16a2c}{Timing\+Budget}} =\mbox{\hyperlink{vl53l1__platform_8h_a9185a399bbb7fe5fe82192611a310da7}{VL53\+L1\+\_\+\+\_\+\+TIMING\+\_\+\+BUDGET}}
\item 
int16\+\_\+t \mbox{\hyperlink{z__vl53l1x__test_8c_aac41a7948e7297c7e10a989bb9fa52ed}{Calib\+Offset}} =\mbox{\hyperlink{vl53l1__platform_8h_aaed0db200f0c6f5bffacc9c6b672944f}{VL53\+L1\+\_\+\+\_\+\+CALIB\+\_\+\+OFFSET}}
\item 
uint16\+\_\+t \mbox{\hyperlink{z__vl53l1x__test_8c_a750af56cecd795f4492807bf7b8d2264}{Distance\+Mode}} =\mbox{\hyperlink{vl53l1__platform_8h_abe4fdcb5c3fc3d125497e417ff23e5f6}{VL53\+L1\+\_\+\+\_\+\+DISTANCE\+\_\+\+MODE}}
\item 
uint8\+\_\+t \mbox{\hyperlink{z__vl53l1x__test_8c_a1459d9b758a3fe8080e595d9904f8ec2}{Error\+Perc}} =0
\item 
uint32\+\_\+t \mbox{\hyperlink{z__vl53l1x__test_8c_aed1fc84ecdc50e67f8f8e523e570947a}{numerrors}} =0
\item 
uint32\+\_\+t \mbox{\hyperlink{z__vl53l1x__test_8c_a5ac9f67bca34dd0dbcbc44a43b422fda}{read\+Counter}} =0
\item 
float \mbox{\hyperlink{z__vl53l1x__test_8c_a1af261344ec9d438bf2f6504a8b1dafd}{avg\+Dist}}
\item 
float \mbox{\hyperlink{z__vl53l1x__test_8c_a1245bd8b012c0b49ec389e631081ffe5}{Std\+Dev}}
\end{DoxyCompactItemize}

\doxysubsection{Documentation des macros}
\Hypertarget{z__vl53l1x__test_8c_a14df6345e8d840e0fa519bea201e4988}\index{z\_vl53l1x\_test.c@{z\_vl53l1x\_test.c}!DIM\_ARR@{DIM\_ARR}}
\index{DIM\_ARR@{DIM\_ARR}!z\_vl53l1x\_test.c@{z\_vl53l1x\_test.c}}
\doxysubsubsection{\texorpdfstring{DIM\_ARR}{DIM\_ARR}}
{\footnotesize\ttfamily \label{z__vl53l1x__test_8c_a14df6345e8d840e0fa519bea201e4988} 
\#define DIM\+\_\+\+ARR~100}

\doxysubsection{Documentation des fonctions}
\Hypertarget{z__vl53l1x__test_8c_a03928b0a24d7f6c4719ee98a56c976fc}\index{z\_vl53l1x\_test.c@{z\_vl53l1x\_test.c}!VL53L1\_\_test@{VL53L1\_\_test}}
\index{VL53L1\_\_test@{VL53L1\_\_test}!z\_vl53l1x\_test.c@{z\_vl53l1x\_test.c}}
\doxysubsubsection{\texorpdfstring{VL53L1\_\_test()}{VL53L1\_\_test()}}
{\footnotesize\ttfamily \label{z__vl53l1x__test_8c_a03928b0a24d7f6c4719ee98a56c976fc} 
void VL53\+L1\+\_\+\+\_\+test (\begin{DoxyParamCaption}{}{}\end{DoxyParamCaption})}

\doxysubsection{Documentation des variables}
\Hypertarget{z__vl53l1x__test_8c_adaa0bc111b1e10351bb55566a2b5ce5b}\index{z\_vl53l1x\_test.c@{z\_vl53l1x\_test.c}!AmbientPerSpad@{AmbientPerSpad}}
\index{AmbientPerSpad@{AmbientPerSpad}!z\_vl53l1x\_test.c@{z\_vl53l1x\_test.c}}
\doxysubsubsection{\texorpdfstring{AmbientPerSpad}{AmbientPerSpad}}
{\footnotesize\ttfamily \label{z__vl53l1x__test_8c_adaa0bc111b1e10351bb55566a2b5ce5b} 
uint16\+\_\+t Ambient\+Per\+Spad}

\Hypertarget{z__vl53l1x__test_8c_ae9883292894ff2fabeea816fa0487cca}\index{z\_vl53l1x\_test.c@{z\_vl53l1x\_test.c}!AmbientRate@{AmbientRate}}
\index{AmbientRate@{AmbientRate}!z\_vl53l1x\_test.c@{z\_vl53l1x\_test.c}}
\doxysubsubsection{\texorpdfstring{AmbientRate}{AmbientRate}}
{\footnotesize\ttfamily \label{z__vl53l1x__test_8c_ae9883292894ff2fabeea816fa0487cca} 
uint16\+\_\+t Ambient\+Rate}

\Hypertarget{z__vl53l1x__test_8c_a1af261344ec9d438bf2f6504a8b1dafd}\index{z\_vl53l1x\_test.c@{z\_vl53l1x\_test.c}!avgDist@{avgDist}}
\index{avgDist@{avgDist}!z\_vl53l1x\_test.c@{z\_vl53l1x\_test.c}}
\doxysubsubsection{\texorpdfstring{avgDist}{avgDist}}
{\footnotesize\ttfamily \label{z__vl53l1x__test_8c_a1af261344ec9d438bf2f6504a8b1dafd} 
float avg\+Dist}

\Hypertarget{z__vl53l1x__test_8c_aac41a7948e7297c7e10a989bb9fa52ed}\index{z\_vl53l1x\_test.c@{z\_vl53l1x\_test.c}!CalibOffset@{CalibOffset}}
\index{CalibOffset@{CalibOffset}!z\_vl53l1x\_test.c@{z\_vl53l1x\_test.c}}
\doxysubsubsection{\texorpdfstring{CalibOffset}{CalibOffset}}
{\footnotesize\ttfamily \label{z__vl53l1x__test_8c_aac41a7948e7297c7e10a989bb9fa52ed} 
int16\+\_\+t Calib\+Offset =\mbox{\hyperlink{vl53l1__platform_8h_aaed0db200f0c6f5bffacc9c6b672944f}{VL53\+L1\+\_\+\+\_\+\+CALIB\+\_\+\+OFFSET}}}

\Hypertarget{z__vl53l1x__test_8c_a23eaf4ad03dd3ea6ccca26824b589ba1}\index{z\_vl53l1x\_test.c@{z\_vl53l1x\_test.c}!Distance@{Distance}}
\index{Distance@{Distance}!z\_vl53l1x\_test.c@{z\_vl53l1x\_test.c}}
\doxysubsubsection{\texorpdfstring{Distance}{Distance}}
{\footnotesize\ttfamily \label{z__vl53l1x__test_8c_a23eaf4ad03dd3ea6ccca26824b589ba1} 
uint16\+\_\+t Distance}

\Hypertarget{z__vl53l1x__test_8c_a750af56cecd795f4492807bf7b8d2264}\index{z\_vl53l1x\_test.c@{z\_vl53l1x\_test.c}!DistanceMode@{DistanceMode}}
\index{DistanceMode@{DistanceMode}!z\_vl53l1x\_test.c@{z\_vl53l1x\_test.c}}
\doxysubsubsection{\texorpdfstring{DistanceMode}{DistanceMode}}
{\footnotesize\ttfamily \label{z__vl53l1x__test_8c_a750af56cecd795f4492807bf7b8d2264} 
uint16\+\_\+t Distance\+Mode =\mbox{\hyperlink{vl53l1__platform_8h_abe4fdcb5c3fc3d125497e417ff23e5f6}{VL53\+L1\+\_\+\+\_\+\+DISTANCE\+\_\+\+MODE}}}

\Hypertarget{z__vl53l1x__test_8c_a1459d9b758a3fe8080e595d9904f8ec2}\index{z\_vl53l1x\_test.c@{z\_vl53l1x\_test.c}!ErrorPerc@{ErrorPerc}}
\index{ErrorPerc@{ErrorPerc}!z\_vl53l1x\_test.c@{z\_vl53l1x\_test.c}}
\doxysubsubsection{\texorpdfstring{ErrorPerc}{ErrorPerc}}
{\footnotesize\ttfamily \label{z__vl53l1x__test_8c_a1459d9b758a3fe8080e595d9904f8ec2} 
uint8\+\_\+t Error\+Perc =0}

\Hypertarget{z__vl53l1x__test_8c_aed1fc84ecdc50e67f8f8e523e570947a}\index{z\_vl53l1x\_test.c@{z\_vl53l1x\_test.c}!numerrors@{numerrors}}
\index{numerrors@{numerrors}!z\_vl53l1x\_test.c@{z\_vl53l1x\_test.c}}
\doxysubsubsection{\texorpdfstring{numerrors}{numerrors}}
{\footnotesize\ttfamily \label{z__vl53l1x__test_8c_aed1fc84ecdc50e67f8f8e523e570947a} 
uint32\+\_\+t numerrors =0}

\Hypertarget{z__vl53l1x__test_8c_a850e4e5b2c2319b8168134e8397f69f0}\index{z\_vl53l1x\_test.c@{z\_vl53l1x\_test.c}!RangeStatus@{RangeStatus}}
\index{RangeStatus@{RangeStatus}!z\_vl53l1x\_test.c@{z\_vl53l1x\_test.c}}
\doxysubsubsection{\texorpdfstring{RangeStatus}{RangeStatus}}
{\footnotesize\ttfamily \label{z__vl53l1x__test_8c_a850e4e5b2c2319b8168134e8397f69f0} 
uint8\+\_\+t Range\+Status}

\Hypertarget{z__vl53l1x__test_8c_a5ac9f67bca34dd0dbcbc44a43b422fda}\index{z\_vl53l1x\_test.c@{z\_vl53l1x\_test.c}!readCounter@{readCounter}}
\index{readCounter@{readCounter}!z\_vl53l1x\_test.c@{z\_vl53l1x\_test.c}}
\doxysubsubsection{\texorpdfstring{readCounter}{readCounter}}
{\footnotesize\ttfamily \label{z__vl53l1x__test_8c_a5ac9f67bca34dd0dbcbc44a43b422fda} 
uint32\+\_\+t read\+Counter =0}

\Hypertarget{z__vl53l1x__test_8c_abafcbdae32d0e890623e3c43e0b33afc}\index{z\_vl53l1x\_test.c@{z\_vl53l1x\_test.c}!SignalPerSpad@{SignalPerSpad}}
\index{SignalPerSpad@{SignalPerSpad}!z\_vl53l1x\_test.c@{z\_vl53l1x\_test.c}}
\doxysubsubsection{\texorpdfstring{SignalPerSpad}{SignalPerSpad}}
{\footnotesize\ttfamily \label{z__vl53l1x__test_8c_abafcbdae32d0e890623e3c43e0b33afc} 
uint16\+\_\+t Signal\+Per\+Spad}

\Hypertarget{z__vl53l1x__test_8c_ae0e1cab1c8d7bc781ec32fffee47dec4}\index{z\_vl53l1x\_test.c@{z\_vl53l1x\_test.c}!SignalRate@{SignalRate}}
\index{SignalRate@{SignalRate}!z\_vl53l1x\_test.c@{z\_vl53l1x\_test.c}}
\doxysubsubsection{\texorpdfstring{SignalRate}{SignalRate}}
{\footnotesize\ttfamily \label{z__vl53l1x__test_8c_ae0e1cab1c8d7bc781ec32fffee47dec4} 
uint16\+\_\+t Signal\+Rate}

\Hypertarget{z__vl53l1x__test_8c_a1245bd8b012c0b49ec389e631081ffe5}\index{z\_vl53l1x\_test.c@{z\_vl53l1x\_test.c}!StdDev@{StdDev}}
\index{StdDev@{StdDev}!z\_vl53l1x\_test.c@{z\_vl53l1x\_test.c}}
\doxysubsubsection{\texorpdfstring{StdDev}{StdDev}}
{\footnotesize\ttfamily \label{z__vl53l1x__test_8c_a1245bd8b012c0b49ec389e631081ffe5} 
float Std\+Dev}

\Hypertarget{z__vl53l1x__test_8c_ac59106b4c004961b1bc62f7e05b16a2c}\index{z\_vl53l1x\_test.c@{z\_vl53l1x\_test.c}!TimingBudget@{TimingBudget}}
\index{TimingBudget@{TimingBudget}!z\_vl53l1x\_test.c@{z\_vl53l1x\_test.c}}
\doxysubsubsection{\texorpdfstring{TimingBudget}{TimingBudget}}
{\footnotesize\ttfamily \label{z__vl53l1x__test_8c_ac59106b4c004961b1bc62f7e05b16a2c} 
uint16\+\_\+t Timing\+Budget =\mbox{\hyperlink{vl53l1__platform_8h_a9185a399bbb7fe5fe82192611a310da7}{VL53\+L1\+\_\+\+\_\+\+TIMING\+\_\+\+BUDGET}}}

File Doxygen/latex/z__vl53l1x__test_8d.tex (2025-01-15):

\doxysection{Référence du fichier z\+\_\+vl53l1x\+\_\+test.\+d}
\hypertarget{z__vl53l1x__test_8d}{}\label{z__vl53l1x__test_8d}\index{z\_vl53l1x\_test.d@{z\_vl53l1x\_test.d}}

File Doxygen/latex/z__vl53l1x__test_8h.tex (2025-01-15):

\doxysection{Référence du fichier z\+\_\+vl53l1x\+\_\+test.\+h}
\hypertarget{z__vl53l1x__test_8h}{}\label{z__vl53l1x__test_8h}\index{z\_vl53l1x\_test.h@{z\_vl53l1x\_test.h}}
\doxysubsubsection*{Fonctions}
\begin{DoxyCompactItemize}
\item 
void \mbox{\hyperlink{z__vl53l1x__test_8h_a03928b0a24d7f6c4719ee98a56c976fc}{VL53\+L1\+\_\+\+\_\+test}} ()
\end{DoxyCompactItemize}

\doxysubsection{Documentation des fonctions}
\Hypertarget{z__vl53l1x__test_8h_a03928b0a24d7f6c4719ee98a56c976fc}\index{z\_vl53l1x\_test.h@{z\_vl53l1x\_test.h}!VL53L1\_\_test@{VL53L1\_\_test}}
\index{VL53L1\_\_test@{VL53L1\_\_test}!z\_vl53l1x\_test.h@{z\_vl53l1x\_test.h}}
\doxysubsubsection{\texorpdfstring{VL53L1\_\_test()}{VL53L1\_\_test()}}
{\footnotesize\ttfamily \label{z__vl53l1x__test_8h_a03928b0a24d7f6c4719ee98a56c976fc} 
void VL53\+L1\+\_\+\+\_\+test (\begin{DoxyParamCaption}{}{}\end{DoxyParamCaption})}

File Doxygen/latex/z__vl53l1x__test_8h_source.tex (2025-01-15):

\doxysection{z\+\_\+vl53l1x\+\_\+test.\+h}
\hypertarget{z__vl53l1x__test_8h_source}{}\label{z__vl53l1x__test_8h_source}\index{z\_vl53l1x\_test.h@{z\_vl53l1x\_test.h}}
\mbox{\hyperlink{z__vl53l1x__test_8h}{Aller à la documentation de ce fichier.}}
\begin{DoxyCode}{0}
\DoxyCodeLine{00001\ \textcolor{comment}{/*}}
\DoxyCodeLine{00002\ \textcolor{comment}{\ ******************************************************************************}}
\DoxyCodeLine{00003\ \textcolor{comment}{\ *\ @attention}}
\DoxyCodeLine{00004\ \textcolor{comment}{\ *\ Author:\ CHAIR}}
\DoxyCodeLine{00005\ \textcolor{comment}{\ *\ Copyright\ (c)\ 2024\ STMicroelectronics.}}
\DoxyCodeLine{00006\ \textcolor{comment}{\ *\ All\ rights\ reserved.}}
\DoxyCodeLine{00007\ \textcolor{comment}{\ *}}
\DoxyCodeLine{00008\ \textcolor{comment}{\ *\ This\ software\ is\ licensed\ under\ terms\ that\ can\ be\ found\ in\ the\ LICENSE\ file}}
\DoxyCodeLine{00009\ \textcolor{comment}{\ *\ in\ the\ root\ directory\ of\ this\ software\ component.}}
\DoxyCodeLine{00010\ \textcolor{comment}{\ *\ If\ no\ LICENSE\ file\ comes\ with\ this\ software,\ it\ is\ provided\ AS-\/IS.}}
\DoxyCodeLine{00011\ \textcolor{comment}{\ *}}
\DoxyCodeLine{00012\ \textcolor{comment}{\ ******************************************************************************}}
\DoxyCodeLine{00013\ \textcolor{comment}{\ */}}
\DoxyCodeLine{00018\ \ }
\DoxyCodeLine{00019\ \textcolor{preprocessor}{\#ifndef\ \_Z\_VL53L1\_TEST\_H\_}}
\DoxyCodeLine{00020\ \textcolor{preprocessor}{\#define\ \_Z\_VL53L1\_TEST\_H\_}}
\DoxyCodeLine{00021\ }
\DoxyCodeLine{00022\ \textcolor{keywordtype}{void}\ \mbox{\hyperlink{z__vl53l1x__test_8h_a03928b0a24d7f6c4719ee98a56c976fc}{VL53L1\_\_test}}();}
\DoxyCodeLine{00023\ }
\DoxyCodeLine{00024\ \textcolor{preprocessor}{\#endif}}

\end{DoxyCode}

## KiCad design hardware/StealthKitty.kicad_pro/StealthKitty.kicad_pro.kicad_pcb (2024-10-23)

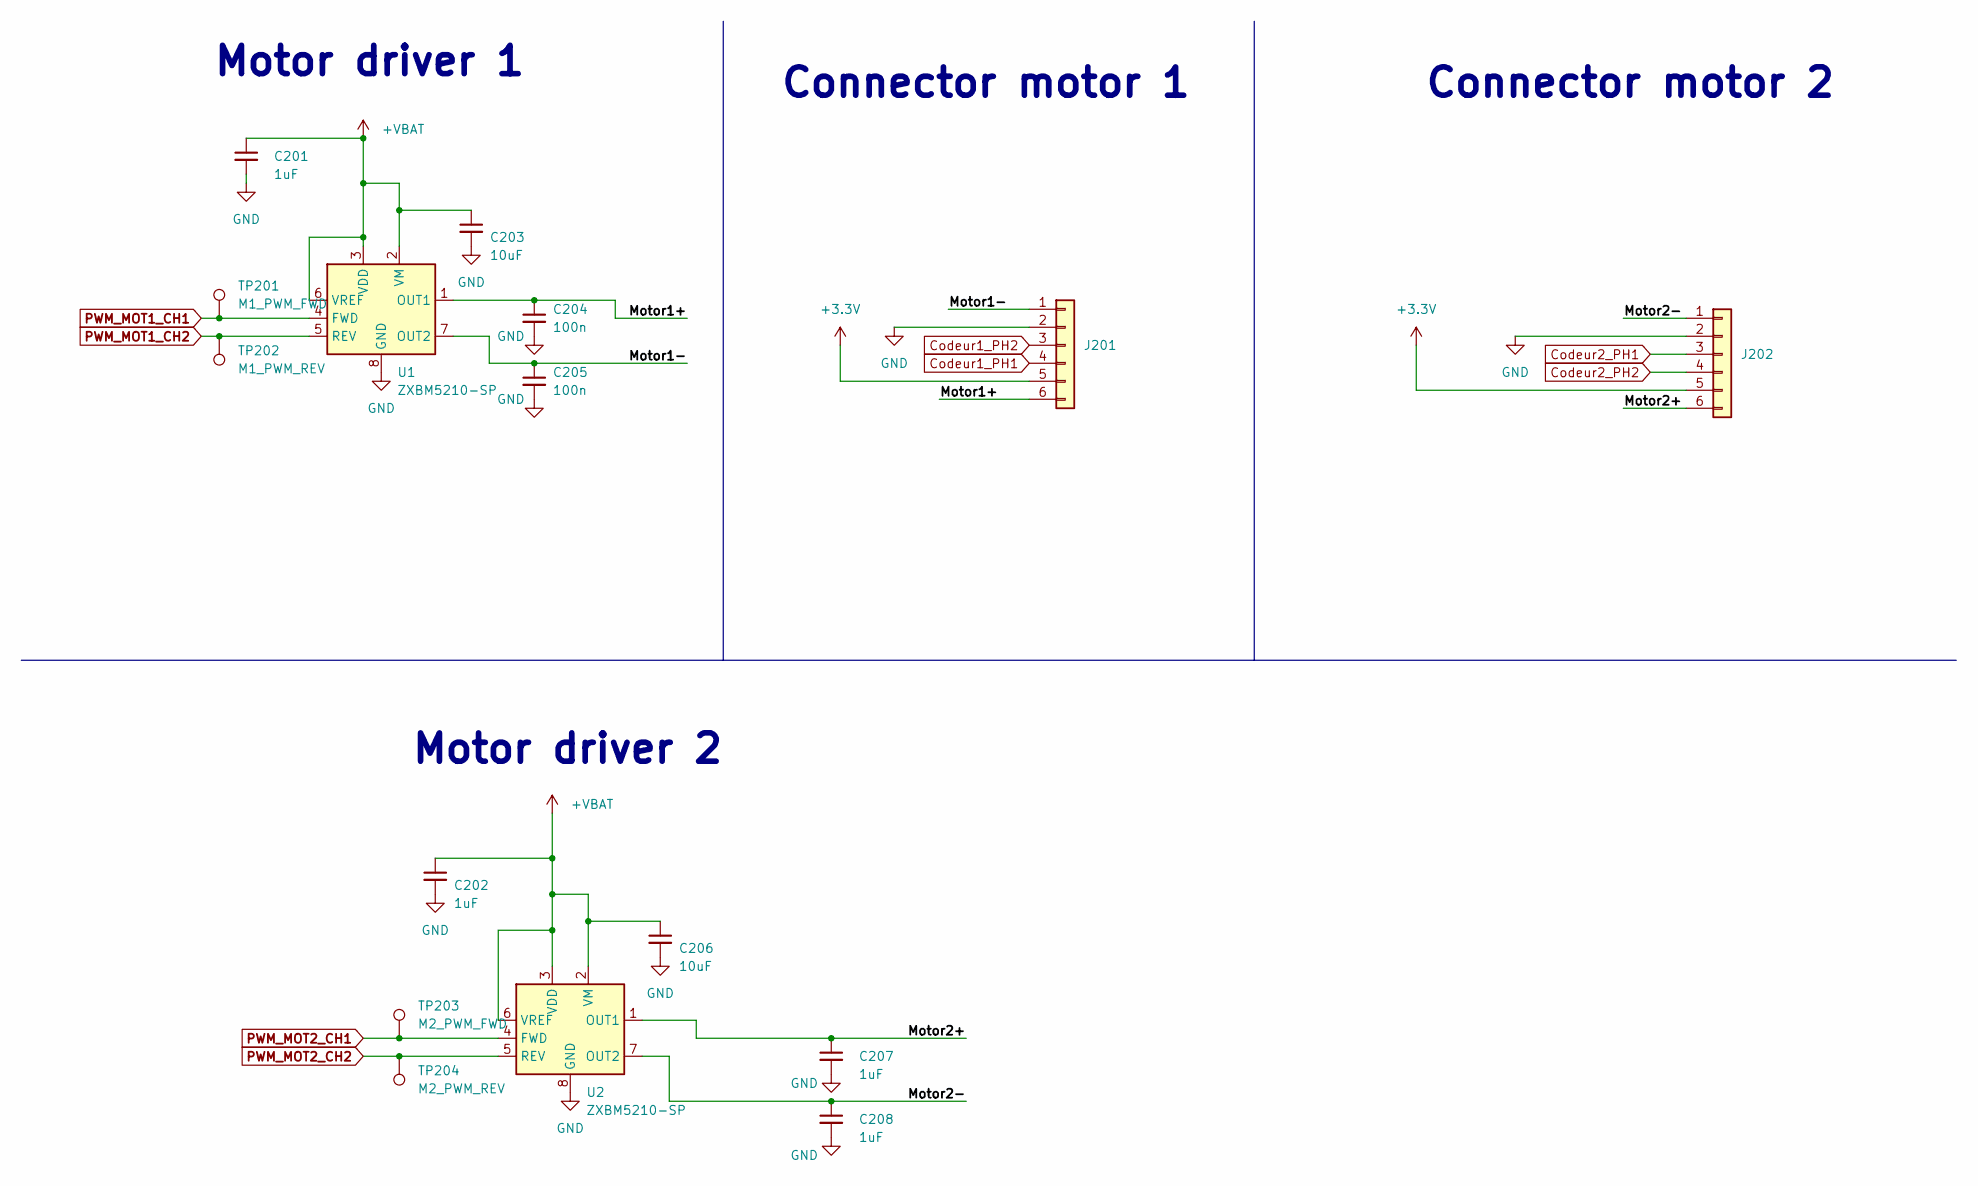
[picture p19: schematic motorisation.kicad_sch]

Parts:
C201, C202, C207, C208: 1uF; C_0603_1608Metric
C203, C206: 10uF; C_0603_1608Metric
C204, C205: 100n; C_0402_1005Metric
J201, J202: Conn_01x06; JST_XH_S6B-XH-A_1x06_P2.50mm_Horizontal
TP201: M1_PWM_FWD; TestPoint_Pad_D1.5mm
TP202: M1_PWM_REV; TestPoint_Pad_D1.5mm
TP203: M2_PWM_FWD; TestPoint_Pad_D1.5mm
TP204: M2_PWM_REV; TestPoint_Pad_D1.5mm
U1, U2: ZXBM5210-SP; Diodes_SO-8EP

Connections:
+3.3V: J201.5, J202.5; also elsewhere on the board
+VBAT: C201.1, C202.1, C203.1, C206.1, U1.2 (VM), U1.3 (VDD), U1.6 (VREF), U2.2 (VM), U2.3 (VDD), U2.6 (VREF); also elsewhere on the board
/Motorisation Sheet/Motor1+: C204.1, J201.6, U1.1 (OUT1)
/Motorisation Sheet/Motor1-: C205.1, J201.1, U1.7 (OUT2)
/Motorisation Sheet/Motor2+: C207.1, J202.6, U2.1 (OUT1)
/Motorisation Sheet/Motor2-: C208.1, J202.1, U2.7 (OUT2)
Codeur1_PH1: J201.4; also elsewhere on the board
Codeur1_PH2: J201.3; also elsewhere on the board
Codeur2_PH1: J202.3; also elsewhere on the board
Codeur2_PH2: J202.4; also elsewhere on the board
GND: C201.2, C202.2, C203.2, C204.2, C205.2, C206.2, C207.2, C208.2, J201.2, J202.2, U1.8 (GND), U1.9 (GND), U2.8 (GND), U2.9 (GND); also elsewhere on the board
PWM_MOT1_CH1: TP201.1, U1.4 (FWD); also elsewhere on the board
PWM_MOT1_CH2: TP202.1, U1.5 (REV); also elsewhere on the board
PWM_MOT2_CH1: TP203.1, U2.4 (FWD); also elsewhere on the board
PWM_MOT2_CH2: TP204.1, U2.5 (REV); also elsewhere on the board

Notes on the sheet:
Motor driver 1
Connector motor 2
Connector motor 1
Motor driver 2

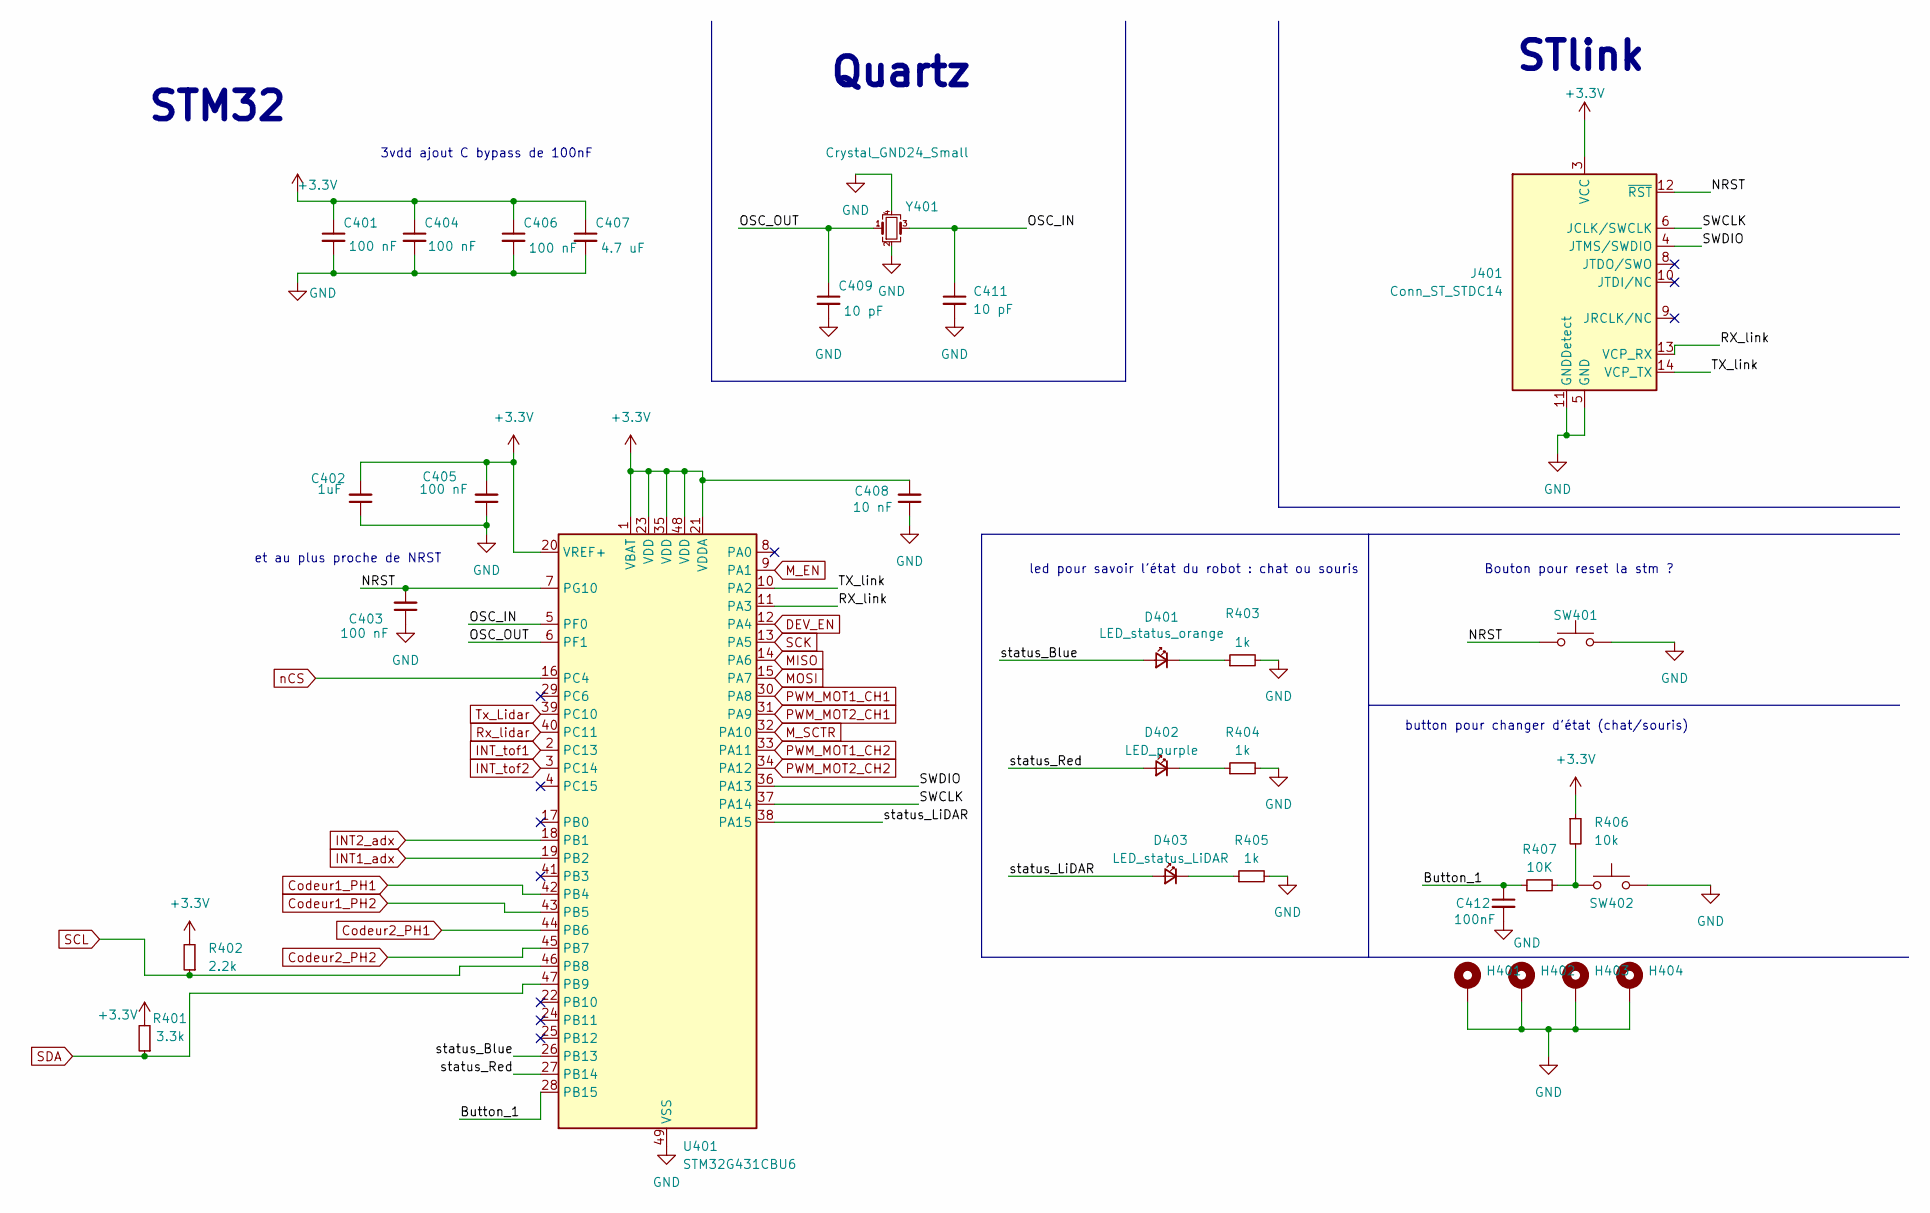
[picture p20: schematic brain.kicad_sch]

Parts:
C401, C403, C404, C405, C406: 100 nF; C_0402_1005Metric
C402: 1uF; C_0603_1608Metric
C407: 4.7 uF; C_0603_1608Metric
C408: 10 nF; C_0402_1005Metric
C409, C411: 10 pF; C_0402_1005Metric
C412: 100nF; C_0402_1005Metric
D401: LED_status_orange; LED_0603_1608Metric_Pad1.05x0.95mm_HandSolder
D402: LED_purple; LED_0603_1608Metric_Pad1.05x0.95mm_HandSolder
D403: LED_status_LiDAR; LED_0603_1608Metric_Pad1.05x0.95mm_HandSolder
H401, H402, H403, H404: MountingHole_3.2mm_M3_Pad_Via
J401: Conn_ST_STDC14; PinHeader_2x07_P1.27mm_Vertical_SMD
R401: 3.3k; R_0402_1005Metric
R402: 2.2k; R_0402_1005Metric
R403, R404, R405: 1k; R_0402_1005Metric
R406: 10k; R_0402_1005Metric
R407: 10K; R_0402_1005Metric
SW401, SW402: SW_Push; SW_Push_1P1T_NO_6x6mm_H9.5mm
U401: STM32G431CBU6; QFN-48-1EP_7x7mm_P0.5mm_EP5.6x5.6mm
Y401: Crystal_GND24_Small; Crystal_SMD_3225-4Pin_3.2x2.5mm

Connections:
+3.3V: C401.1, C402.2, C404.1, C405.2, C406.1, C407.1, C408.2, J401.3 (VCC), R401.2, R402.2, R406.1, U401.1 (VBAT), U401.20 (VREF+), U401.21 (VDDA), U401.23 (VDD), U401.35 (VDD), U401.48 (VDD); also elsewhere on the board
/Brain Sheet/Button_1: C412.1, R407.1, U401.28 (PB15)
/Brain Sheet/NRST: C403.2, J401.12 (~RST), SW401.1, U401.7 (PG10)
/Brain Sheet/OSC_IN: C411.1, U401.5 (PF0), Y401.3
/Brain Sheet/OSC_OUT: C409.1, U401.6 (PF1), Y401.1
/Brain Sheet/RX_link: J401.13 (VCP_RX), U401.11 (PA3)
/Brain Sheet/SWCLK: J401.6 (JCLK/SWCLK), U401.37 (PA14)
/Brain Sheet/SWDIO: J401.4 (JTMS/SWDIO), U401.36 (PA13)
/Brain Sheet/TX_link: J401.14 (VCP_TX), U401.10 (PA2)
/Brain Sheet/status_Blue: D401.2 (A), U401.26 (PB13)
/Brain Sheet/status_LiDAR: D403.2 (A), U401.38 (PA15)
/Brain Sheet/status_Red: D402.2 (A), U401.27 (PB14)
Codeur1_PH1: U401.42 (PB4); also elsewhere on the board
Codeur1_PH2: U401.43 (PB5); also elsewhere on the board
Codeur2_PH1: U401.44 (PB6); also elsewhere on the board
Codeur2_PH2: U401.45 (PB7); also elsewhere on the board
DEV_EN: U401.12 (PA4); also elsewhere on the board
GND: C401.2, C402.1, C403.1, C404.2, C405.1, C406.2, C407.2, C408.1, C409.2, C411.2, C412.2, H401.1, H402.1, H403.1, H404.1, J401.5 (GND), J401.7 (GND), J401.11 (GNDDetect), R403.2, R404.2, R405.2, SW401.2, SW402.2, U401.49 (VSS), Y401.2, Y401.4; also elsewhere on the board
INT1_adx: U401.19 (PB2); also elsewhere on the board
INT2_adx: U401.18 (PB1); also elsewhere on the board
INT_tof1: U401.2 (PC13); also elsewhere on the board
INT_tof2: U401.3 (PC14); also elsewhere on the board
MISO: U401.14 (PA6); also elsewhere on the board
MOSI: U401.15 (PA7); also elsewhere on the board
M_EN: U401.9 (PA1); also elsewhere on the board
M_SCTR: U401.32 (PA10); also elsewhere on the board
unnamed: D401.1 (K), R403.1
unnamed: D402.1 (K), R404.1
unnamed: D403.1 (K), R405.1
unnamed: R406.2, R407.2, SW402.1
PWM_MOT1_CH1: U401.30 (PA8); also elsewhere on the board
PWM_MOT1_CH2: U401.33 (PA11); also elsewhere on the board
PWM_MOT2_CH1: U401.31 (PA9); also elsewhere on the board
PWM_MOT2_CH2: U401.34 (PA12); also elsewhere on the board
Rx_lidar: U401.40 (PC11); also elsewhere on the board
SCK: U401.13 (PA5); also elsewhere on the board
SCL: R402.1, U401.46 (PB8); also elsewhere on the board
SDA: R401.1, U401.47 (PB9); also elsewhere on the board
Tx_Lidar: U401.39 (PC10); also elsewhere on the board
nCS: U401.16 (PC4); also elsewhere on the board

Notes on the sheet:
Quartz
et au plus proche de NRST
STM32
led pour savoir l'état du robot : chat ou souris
3vdd ajout C bypass de 100nF
Bouton pour reset la stm ?
STlink
button pour changer d'état (chat/souris)

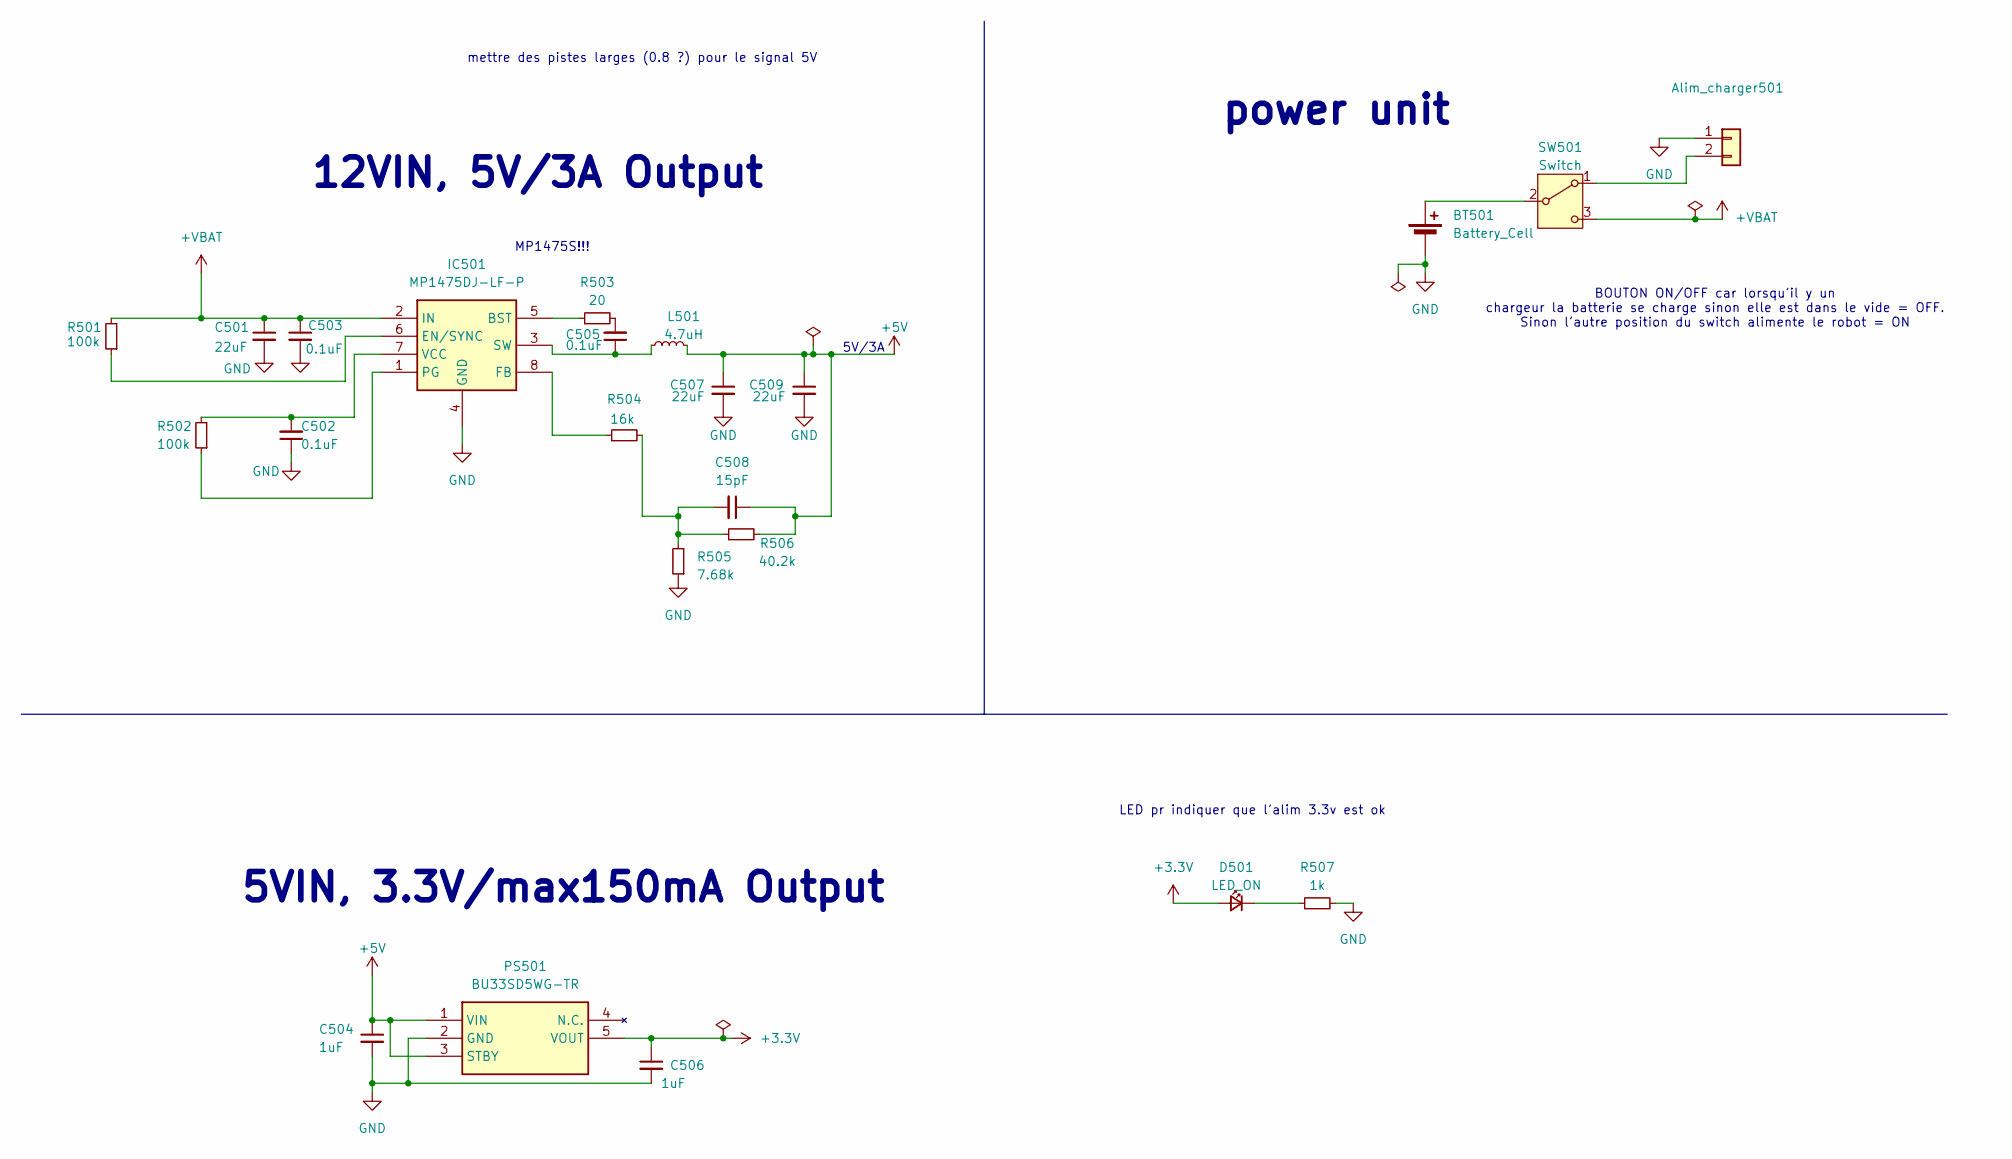
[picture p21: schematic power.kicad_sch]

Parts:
Alim_charger501: Conn_01x02; JST_XH_S2B-XH-A-1_1x02_P2.50mm_Horizontal
BT501: Battery_Cell; JST_XH_S2B-XH-A-1_1x02_P2.50mm_Horizontal
C501, C507, C509: 22uF; C_0805_2012Metric
C502, C503, C505: 0.1uF; C_0402_1005Metric
C504, C506: 1uF; C_0603_1608Metric
C508: 15pF; C_0402_1005Metric
D501: LED_ON; LED_0603_1608Metric_Pad1.05x0.95mm_HandSolder
IC501: MP1475DJ-LF-P; SOT65P280X100-8N; Mouser Part Number 946-MP1475DJLFP
L501: 4.7uH; INDPM5050X200N; Manufacturer_Part_Number 74438356047HT; Mouser Part Number 710-74438356047HT
PS501: BU33SD5WG-TR; SOT95P280X125-5N; Manufacturer_Part_Number BU33SD5WG-TR; Mouser Part Number 755-BU33SD5WG-TR
R501, R502: 100k; R_0402_1005Metric
R503: 20; R_0402_1005Metric
R504: 16k; R_0402_1005Metric
R505: 7.68k; R_0402_1005Metric
R506: 40.2k; R_0402_1005Metric
R507: 1k; R_0402_1005Metric
SW501: Switch; JST_XH_S3B-XH-A-1_1x03_P2.50mm_Horizontal; Manufacturer_Part_Number WS-TOTV Ø 6.35mm; Mouser Part Number 1333652

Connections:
+3.3V: C506.1, D501.2 (A), PS501.5 (VOUT); also elsewhere on the board
+5V: C504.1, C507.1, C508.1, C509.1, L501.2, PS501.1 (VIN), PS501.3 (STBY), R506.2; also elsewhere on the board
+VBAT: C501.1, C503.1, IC501.2 (IN), R501.2, SW501.3 (C); also elsewhere on the board
GND: Alim_charger501.1, BT501.2 (-), C501.2, C502.1, C503.2, C504.2, C506.2, C507.2, C509.2, IC501.4 (GND), PS501.2 (GND), R505.1, R507.2; also elsewhere on the board
unnamed: Alim_charger501.2, SW501.1 (A)
unnamed: BT501.1 (+), SW501.2 (B)
unnamed: C505.2, R503.2
unnamed: C508.2, R504.2, R505.2, R506.1
unnamed: D501.1 (K), R507.1
unnamed: IC501.5 (BST), R503.1
unnamed: IC501.6 (EN/SYNC), R501.1
unnamed: IC501.8 (FB), R504.1
unnamed: IC501.1 (PG), R502.1
unnamed: C505.1, IC501.3 (SW), L501.1
unnamed: C502.2, IC501.7 (VCC), R502.2

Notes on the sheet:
mettre des pistes larges (0.8 ?) pour le signal 5V
12VIN, 5V/3A Output
LED pr indiquer que l'alim 3.3v est ok
5VIN, 3.3V/max150mA Output
MP1475S!!!
5V/3A
power unit
BOUTON ON/OFF car lorsqu'il y un chargeur la batterie se charge sinon elle est dans le vide = OFF. Sinon l'autre position du switch alimente le robot = ON

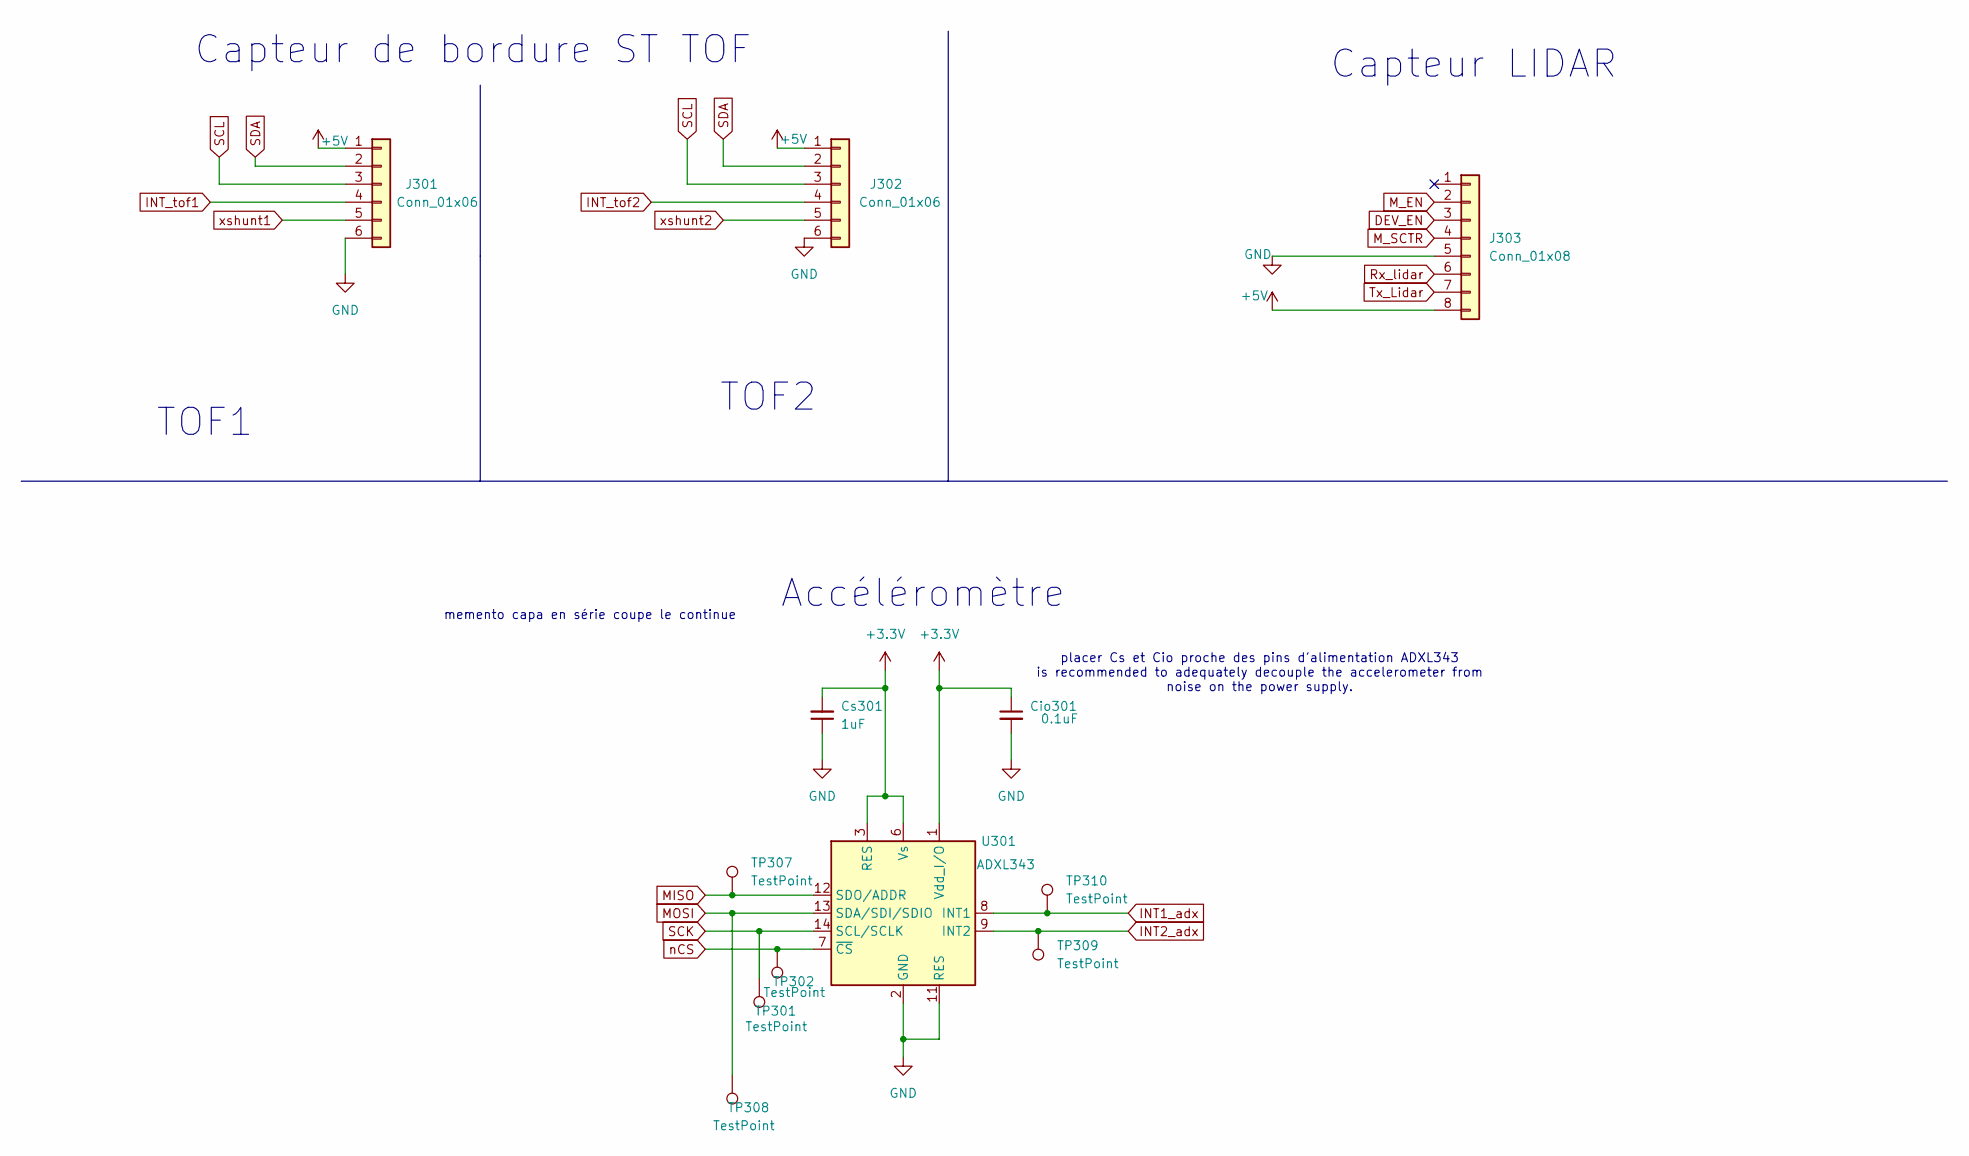
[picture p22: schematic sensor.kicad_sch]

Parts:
Cio301: 0.1uF; C_0402_1005Metric
Cs301: 1uF; C_0603_1608Metric
J301, J302: Conn_01x06; JST_XH_S6B-XH-A_1x06_P2.50mm_Horizontal
J303: Conn_01x08; JST_XH_S8B-XH-A_1x08_P2.50mm_Horizontal
TP301, TP302, TP307, TP308, TP309, TP310: TestPoint; TestPoint_Pad_D1.5mm
U301: ADXL343; LGA-14_3x5mm_P0.8mm_LayoutBorder1x6y

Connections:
+3.3V: Cio301.1, Cs301.2, U301.1 (Vdd_I/O), U301.3 (RES), U301.6 (Vs); also elsewhere on the board
+5V: J301.1, J302.1, J303.8; also elsewhere on the board
DEV_EN: J303.3; also elsewhere on the board
GND: Cio301.2, Cs301.1, J301.6, J302.6, J303.5, U301.2 (GND), U301.4 (GND), U301.5 (GND), U301.11 (RES); also elsewhere on the board
INT1_adx: TP310.1, U301.8 (INT1); also elsewhere on the board
INT2_adx: TP309.1, U301.9 (INT2); also elsewhere on the board
INT_tof1: J301.4; also elsewhere on the board
INT_tof2: J302.4; also elsewhere on the board
MISO: TP307.1, U301.12 (SDO/ADDR); also elsewhere on the board
MOSI: TP308.1, U301.13 (SDA/SDI/SDIO); also elsewhere on the board
M_EN: J303.2; also elsewhere on the board
M_SCTR: J303.4; also elsewhere on the board
Rx_lidar: J303.6; also elsewhere on the board
SCK: TP301.1, U301.14 (SCL/SCLK); also elsewhere on the board
SCL: J301.3, J302.3; also elsewhere on the board
SDA: J301.2, J302.2; also elsewhere on the board
Tx_Lidar: J303.7; also elsewhere on the board
nCS: TP302.1, U301.7 (~CS); also elsewhere on the board
xshunt1: J301.5
xshunt2: J302.5

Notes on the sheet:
TOF1
Accéléromètre
memento capa en série coupe le continue
TOF2
Capteur de bordure ST TOF
placer Cs et Cio proche des pins d'alimentation ADXL343 is recommended to adequately decouple the accelerometer from noise on the power supply.
Capteur LIDAR

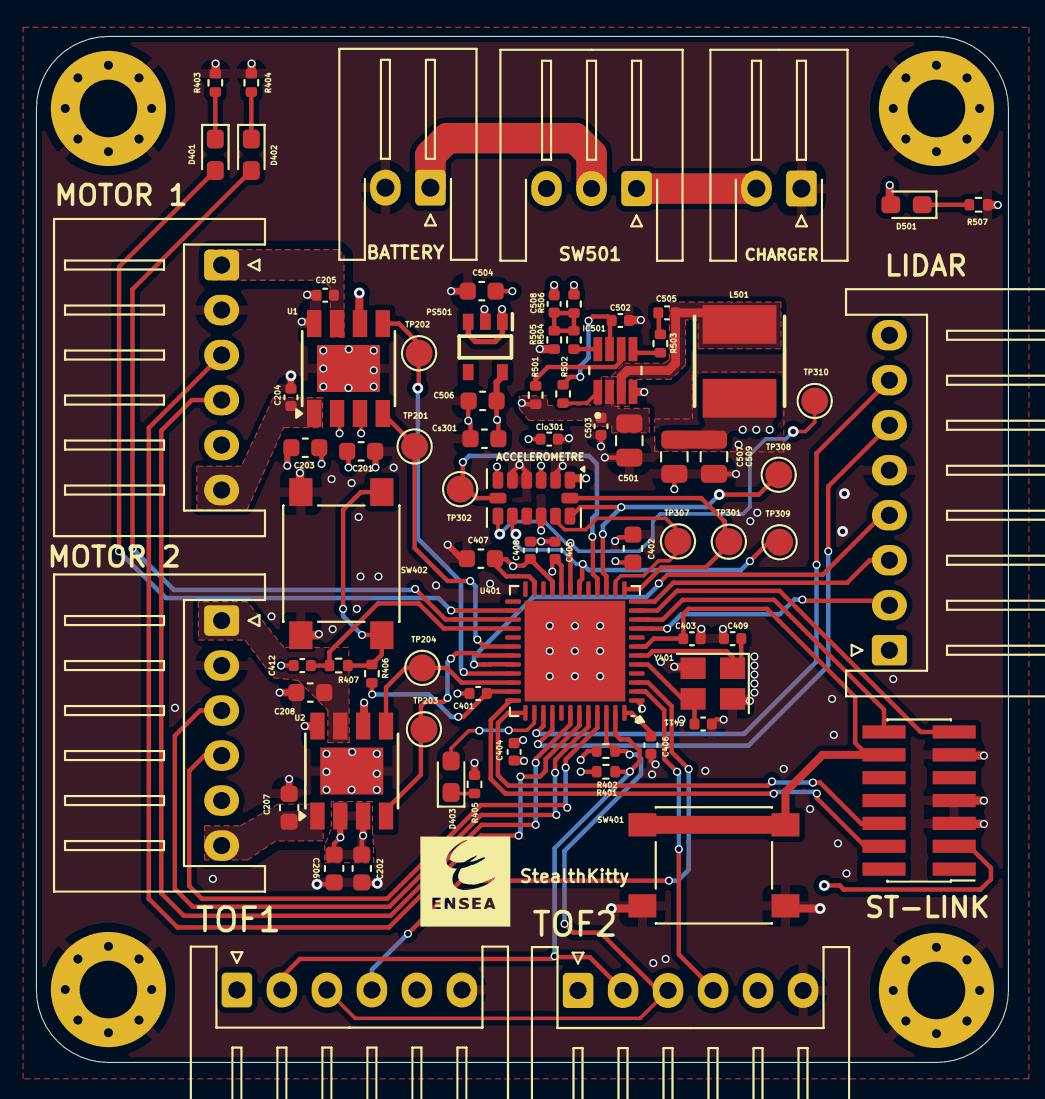
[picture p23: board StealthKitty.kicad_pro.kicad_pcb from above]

Board: 4 copper layers, 54.0 x 57.0 mm, 81 parts (1 on the bottom side), 57 nets.

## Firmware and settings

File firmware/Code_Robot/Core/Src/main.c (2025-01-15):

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
/* Includes ------------------------------------------------------------------*/
#include "main.h"
#include "cmsis_os.h"
#include "dma.h"
#include "i2c.h"
#include "spi.h"
#include "tim.h"
#include "usart.h"
#include "gpio.h"

/* USER CODE BEGIN Includes */
#include "stdio.h"
#include "vl53l1_platform.h"
#include "VL53L1X_api.h"
#include "string.h"
#include "moteur.h"
#include "ADXL343_SPI.h"
#include "drv_LIDAR.h"




/**
 * @brief Redirects printf to UART2 for debugging purposes.
 * @param file: Unused parameter for file descriptor.
 * @param ptr: Pointer to the buffer containing the data to send.
 * @param len: Length of the data to send.
 * @return The number of characters sent.
 */
int _write(int file, char *ptr, int len) {
	HAL_UART_Transmit(&huart2, (uint8_t *)ptr, len, HAL_MAX_DELAY);
	return len;
}

/**
 * Global variables
 */
extern SPI_HandleTypeDef hspi1;
ADXL343 accelerometer;
#define MAX_OBJECTS 100
extern uint8_t g_raw_data[BUFFER_SIZE];
extern int g_current_idx;
extern uint16_t g_PH;
extern uint8_t g_CT;
extern uint8_t g_LSN;
extern uint16_t g_start_angle;
extern uint16_t g_end_angle;
extern uint8_t g_packet_data[PACKET_SIZE];
extern int g_object_angles[MAX_OBJECTS];
extern int g_object_distances[MAX_OBJECTS];
extern int g_obj_count;




/* USER CODE END Includes */

/* USER CODE BEGIN PD */

/* Configuration FreeRTOS */
#define STACK_SIZE 256
/* USER CODE END PD */


/* USER CODE BEGIN PV */

TaskHandle_t h_task_bord = NULL; /**< Task handle for managing a specific task. */


int frame_start = 0; /**< Start index of the LIDAR frame. */
int frame_end = 0; /**< End index of the LIDAR frame. */

int dist_min = 0; /**< Minimum detected distance. */
int idx_min = 0; /**< Index of the closest detected object. */

SemaphoreHandle_t SemHalfCallBack; /**< Semaphore for half DMA completion. */
SemaphoreHandle_t SemClpCallBack; /**< Semaphore for complete DMA transfer. */

/* USER CODE END PV */

/**
 * @brief Configures the system clock.
 */
void SystemClock_Config(void);
/**
 * @brief Initializes FreeRTOS objects.
 */
void MX_FREERTOS_Init(void);
/* USER CODE BEGIN PFP */
int uart_it_transmit_local(uint8_t *p_data, uint16_t size) {
    HAL_UART_Transmit_IT(&huart4, p_data, size);
    return 0;
}

int uart_dma_transmit_local(uint8_t *p_data, uint16_t size) {
    HAL_UART_Transmit_DMA(&huart4, p_data, size);
    return 0;
}

int uart_poll_receive_local(uint8_t *p_data, uint16_t size) {
    HAL_UART_Receive(&huart4, p_data, size, HAL_MAX_DELAY);
    return 0;
}

int uart_it_receive_local(uint8_t *p_data, uint16_t size) {
    HAL_UART_Receive_IT(&huart4, p_data, size);
    return 0;
}
//void Task_MotorControl(void *argument);
/* USER CODE END PFP */

/* USER CODE BEGIN 0 */
void SystemClock_Config(void);
/* USER CODE BEGIN 0 */

/*-----------------------------------------Test---------------------------------------*/
/*void task_Bord(void * unused)
{
	printf("task_Bord démarrée.\n");
	for(;;) {
		ulTaskNotifyTake(pdTRUE, portMAX_DELAY);
		VL53L1X_ClearInterrupt(TOF_ADDR);
		printf(" Attention, seuil franchi !\n");
		VL53L1X_ClearInterrupt(TOF_ADDR);
	}
}*/

/*
void task_SensorMeasurement(void *unused) {
	printf("task_SensorMeasurement démarrée.\n");
	uint16_t distance ;
	uint8_t rangeStatus = 0;

	while (1) {
		VL53L1X_CheckForDataReady(TOF_ADDR, &rangeStatus);
		if (rangeStatus == 0) {
			VL53L1X_GetDistance(TOF_ADDR, &distance);
			printf("Distance mesurée : %d mm\n", distance);
		}
		vTaskDelay(pdMS_TO_TICKS(500));
	}
}
 */

/*void Task_MotorControl(void *argument) {

	printf("Tâche MotorControl démarrée.\n");
	// Choisissez un alpha adapté à la PWM
	uint16_t alpha = 1200;  // 30% de 8500
	uint16_t distance = 0;  // Distance mesurée par le capteur
	const uint32_t delta_time_ms = 50;  // Intervalle de temps pour le calcul
	const uint16_t encoder_resolution = 1024;  // Nombre d'impulsions par tour

	for (;;) {
		// Lire la distance avec VL53L1X
		if (VL53L1X_GetDistance(TOF_ADDR, &distance) == 0) {
			printf("Distance mesurée : %d mm\n", distance);

			// Vérifier si la distance dépasse le seuil critique
			if (distance > 250) {
				// Arrêter les moteurs
				stop_r();
				stop_l();
				printf("Danger détecté : moteur arrêté. Pivot arrière en cours...\n");

				// Effectuer un pivot en arrière
				reverse_r(alpha + 3050);       // Moteur droit recule
				reverse_l(alpha );   // Moteur gauche recule plus lentement pour pivoter
				vTaskDelay(pdMS_TO_TICKS(600)); // Pivot pendant 1,5 seconde

				// Arrêter les moteurs après le pivot
				stop_r();
				stop_l();
				vTaskDelay(pdMS_TO_TICKS(200));
				forward_r(alpha+ 2450);
				vTaskDelay(pdMS_TO_TICKS(320));
				printf("Pivot terminé, moteurs arrêtés.\n");
			} else {
				forward_r(alpha + 1650);
				forward_l(alpha+ 150);

				// Calcul et affichage des vitesses
				float speed_left = calculate_motor_speed(MOTOR_LEFT, delta_time_ms, encoder_resolution);
				float speed_right = calculate_motor_speed(MOTOR_RIGHT, delta_time_ms, encoder_resolution);

				printf("Vitesse moteur gauche : %.2f tours/s\n", speed_left);
				printf("Vitesse moteur droit : %.2f tours/s\n", speed_right);
			}
		} else {
			printf("Erreur : lecture de la distance impossible.\n");
		}
		printf("Position moteur gauche : %d\n", __HAL_TIM_GET_COUNTER(&htim3));
		printf("Position moteur droit : %d\n", __HAL_TIM_GET_COUNTER(&htim4));


		vTaskDelay(pdMS_TO_TICKS(delta_time_ms)); // Vérification toutes les 100 ms
	}
}*/
/*----------------------------------------Fin-------------------------------------------*/


/**
 * @brief Task to manage the ADXL343 accelerometer.
 * @param argument: Pointer to the task arguments (if any).
 */
void vTaskADX(void *argument)
{
	// Initialisation de l'accéléromètre
	ADXL343_initialization(&hspi1, &accelerometer);
	ADXL343_EnableTapInterrupts(&accelerometer);
	ADXL343_set_tap_parameters(&accelerometer, 20, 1, 80, 200);
	ADXL343_SetDataFormat(&hspi1, 0x03); // Configurer en ±16g

	// Variables pour suivre l'état des LEDs et le mode moteur
	uint8_t led_state = 0;    // 0 = rouge, 1 = bleu
	uint8_t motor_mode = 0;  // 0 = souris, 1 = prédateur

	printf("Tâche ADXL343 démarrée. Attente des tapotements...\n");

	while (1)
	{
		// Attente de détection de tap
		vTaskDelay(pdMS_TO_TICKS(500));

		// Si un tap est détecté
		if (ADXL343_check_tap(&accelerometer)) {
			// Alterner les LEDs
			if (led_state == 0) {
				HAL_GPIO_WritePin(GPIOB, Status_Red_Pin, GPIO_PIN_SET);    // LED rouge ON
				HAL_GPIO_WritePin(GPIOB, Status_Blue_Pin, GPIO_PIN_RESET); // LED bleue OFF
				led_state = 1;
			} else {
				HAL_GPIO_WritePin(GPIOB, Status_Red_Pin, GPIO_PIN_RESET); // LED rouge OFF
				HAL_GPIO_WritePin(GPIOB, Status_Blue_Pin, GPIO_PIN_SET);  // LED bleue ON
				led_state = 0;
			}

			// Alterner le mode moteur
			if (motor_mode == 0)
			{
				vTaskDelay(pdMS_TO_TICKS(1000));
				printf("Mode Prédateur activé.\n");
				motorcontrol_predateur(); // Activer le mode prédateur
				motor_mode = 1;
			}
			else
			{
				vTaskDelay(pdMS_TO_TICKS(1000));
				printf("Mode Souris activé.\n");
				motorcontrol_souris(); // Activer le mode souris
				motor_mode = 0;
			}
		}
	}
}

/**
 * @brief Task for the VL53L1X ToF sensor.
 * @param argument: Pointer to the task arguments (if any).
 */

void vTaskToF(void *argument) {
	uint16_t distance;
	uint8_t range_status;

	while (1) {
		// Vérifier la disponibilité des données
		VL53L1X_CheckForDataReady(TOF_ADDR, &range_status);
		if (range_status == 0) {
			VL53L1X_GetDistance(TOF_ADDR, &distance);
			printf("Distance mesurée : %d mm\n", distance);

			if (distance > 250) {
				pivot(); // Effectuer un pivot
			}
		}
		vTaskDelay(pdMS_TO_TICKS(500)); // Vérification rapide
	}
}


/**
 * @brief Tâche pour gérer le LIDAR et les moteurs.
 */
void TaskLIDAR(void * pvParameters) {

	// Paramètres d'asservissement
//	const int VITESSE_BASE = 400;     // Vitesse nominale
//	const int VITESSE_MAX = 800;      // Vitesse maximale
//	const float Kp = 2.0;             // Gain proportionnel
//
//	// Variables de contrôle
//	uint16_t alpha1 = 0, alpha2 = 0;  // Commandes moteurs
//	uint16_t angle = 0;               // Angle mesuré
//	uint16_t vitesse = 0;             // Distance mesurée
//	int16_t erreur_angle = 0;         // Erreur en angle
//	int16_t correction = 0;           // Correction à appliquer
//	const uint8_t cat = 1;            // 1 = mode chat, 0 = mode souris

	// Variables de traitement de trame
	int frame_start = 0;
	int frame_end = 0;
	int dist_min = 0;
	int idx_min = 0;

	// Initialisation des moteurs
//	DRV_MOT_Init(&motor_left, MTR1_CHANNEL);
//	DRV_MOT_Init(&motor_right, MTR2_CHANNEL);

	printf("Démarrage de la tâche d'asservissement sur LIDAR\r\n");

	for(;;) {
		// Attente du signal de demi-buffer DMA rempli
		xSemaphoreTake(SemHalfCallBack, portMAX_DELAY);

		// Parcours du buffer complet
		for(int i=0; i<BUFFER_SIZE; i++) {
			// Attente seconde moitié buffer
			if(i == BUFFER_SIZE/2) {
				xSemaphoreTake(SemClpCallBack, portMAX_DELAY);
			}

			// Détection en-tête de trame
			if(i == 0) {
				if((g_raw_data[i] == 0xA5) && (g_raw_data[i+1] == 0x5A) &&
						(g_raw_data[i+2] == 0x05) && (g_raw_data[i+3] == 0x00) &&
						(g_raw_data[i+4] == 0x00) && (g_raw_data[i+5] == 0x40) &&
						(g_raw_data[i+6] == 0x81)) {
					printf("Device Response Received\r\n");
					g_current_idx = 0;
					i = 6;
					frame_start = 7;
					frame_end = frame_start + 4;
				}
			}

			// Machine à états pour le parsing
			if(i == frame_start) {
				g_PH = g_raw_data[i];  // Octet bas PH
			}
			else if(i == frame_start + 1) {
				g_PH |= (g_raw_data[i] << 8);  // Octet haut PH
			}
			else if(i == frame_start + 2) {
				g_CT = g_raw_data[i];  // Type de paquet
			}
			else if(i == frame_start + 3) {
				frame_end = frame_start + 9 + 2*g_raw_data[i];
				g_LSN = g_raw_data[i];  // Nombre d'échantillons
			}
			else if(i == frame_start + 4) {
				g_start_angle = g_raw_data[i];  // Angle début bas
			}
			else if(i == frame_start + 5) {
				g_start_angle |= (g_raw_data[i] << 8);  // Angle début haut
			}
			else if(i == frame_start + 6) {
				g_end_angle = g_raw_data[i];  // Angle fin bas
			}
			else if(i == frame_start + 7) {
				g_end_angle |= (g_raw_data[i] << 8);  // Angle fin haut
			}
			else if(i == frame_end) {
				g_packet_data[g_current_idx++] = g_raw_data[i];

				// Traitement trame complète
				if(frame_end - frame_start > 11) {
					lidar_parse_data();
					smooth_data();
					detect_objects();
				}

				// Préparation prochaine trame
				g_current_idx = 0;
				frame_start = frame_end + 1;
				frame_end = frame_start + 4;
			}
			else {
				// Stockage données intermédiaires
				g_packet_data[g_current_idx++] = g_raw_data[i];
			}
		}

		// Ajustement indices pour prochain cycle
		frame_start -= BUFFER_SIZE;
		frame_end -= BUFFER_SIZE;

		// Recherche objet le plus proche
		printf("#\r\n");
		dist_min = 2000;
		idx_min = 0;

		for(int i=0; i < g_obj_count; i++) {
			printf("%d,%d\r\n", g_object_angles[i], g_object_distances[i]);

			if(g_object_distances[i] < dist_min && g_object_distances[i] != 0) {
				dist_min = g_object_distances[i];
				idx_min = i;
			}
		}

		//        // Récupération données objet le plus proche
		//        vitesse = g_object_distances[idx_min];
		//        angle = g_object_angles[idx_min];
		//
		//        printf("Objet Cible - Angle: %d°, Distance: %dmm\r\n", angle, vitesse);
		//
		//        if(cat) {
		//            // Mode CHAT : Poursuite de cible
		//            // Normalisation angle [-180°, 180°]
		//            if(angle > 180) {
		//                erreur_angle = angle - 360;
		//            } else {
		//                erreur_angle = angle;
		//            }
		//
		//            // Calcul correction proportionnelle
		//            correction = (int)(Kp * erreur_angle);
		//
		//            // Calcul vitesses moteurs
		//            alpha1 = VITESSE_BASE + correction;
		//            alpha2 = VITESSE_BASE - correction;
		//
		//            // Limitation vitesses
		//            if(alpha1 > VITESSE_MAX) alpha1 = VITESSE_MAX;
		//            if(alpha2 > VITESSE_MAX) alpha2 = VITESSE_MAX;
		//            if(alpha1 < 0) alpha1 = 0;
		//            if(alpha2 < 0) alpha2 = 0;
		//
		//            // Configuration sens rotation
		//            DRV_MOT_startMot_fwd(&motor_right);
		//            DRV_MOT_startMot_rev(&motor_left);
		//
		//            printf("Mode CHAT - Poursuite de la cible\r\n");
		//        } else {
		//            // Mode SOURIS : Fuite
		//            angle = (angle + 180) % 360;
		//
		//            if(angle > 180) {
		//                erreur_angle = angle - 360;
		//            } else {
		//                erreur_angle = angle;
		//            }
		//
		//            correction = (int)(Kp * erreur_angle);
		//
		//            alpha1 = VITESSE_BASE + correction;
		//            alpha2 = VITESSE_BASE - correction;
		//
		//            if(alpha1 > VITESSE_MAX) alpha1 = VITESSE_MAX;
		//            if(alpha2 > VITESSE_MAX) alpha2 = VITESSE_MAX;
		//            if(alpha1 < 0) alpha1 = 0;
		//            if(alpha2 < 0) alpha2 = 0;
		//
		//            DRV_MOT_startMot_rev(&motor_right);
		//            DRV_MOT_startMot_fwd(&motor_left);
		//
		//            printf("Mode SOURIS - Fuite de la cible\r\n");
		//        }
		//
		//        // Application vitesses aux moteurs
		//        DRV_MOT_SetSpeed(&motor_left, alpha1);
		//        DRV_MOT_SetSpeed(&motor_right, alpha2);
		//
		//        HAL_Delay(100);
		//
		//        printf("Commandes moteurs - Gauche: %d, Droite: %d\r\n", alpha1, alpha2);
	}
}


/* USER CODE END 0 */

/**
 * @brief  The application entry point.
 * @retval int
 */
int main(void)
{

	/* USER CODE BEGIN 1 */
	TaskHandle_t xHandleSensor = NULL;
	BaseType_t ret;
	/* USER CODE END 1 */

	/* MCU Configuration--------------------------------------------------------*/

	/* Reset of all peripherals, Initializes the Flash interface and the Systick. */
	HAL_Init();

	/* Configure the system clock */
	SystemClock_Config();

	/* Initialize all configured peripherals */
	MX_GPIO_Init();
	MX_DMA_Init();
	MX_I2C1_Init();
	MX_SPI1_Init();
	MX_USART2_UART_Init();
	MX_TIM1_Init();
	MX_TIM3_Init();
	MX_TIM4_Init();
	MX_UART4_Init();

	/* USER CODE BEGIN 2 */

	// Configuration des callbacks de communication
//	// Assigner les fonctions UART aux pointeurs globaux
//	extern int (*uart_transmit)(uint8_t *p_data, uint16_t size);
//	extern int (*uart_poll_receive)(uint8_t *p_data, uint16_t size);
//	extern int (*uart_it_receive)(uint8_t *p_data, uint16_t size);
//	extern int (*uart_dma_receive)(uint8_t *p_data, uint16_t size);
//	extern int (*uart_it_transmit)(uint8_t *p_data, uint16_t size);
//	extern int (*uart_dma_transmit)(uint8_t *p_data, uint16_t size);
//
//	// Initialisation des pointeurs
//	uart_it_transmit = uart_it_transmit_local;
//	uart_dma_transmit = uart_dma_transmit_local;
//	uart_poll_receive = uart_poll_receive_local;
//	uart_it_receive = uart_it_receive_local;
//
//	// Démarrage du LIDAR et configuration DMA
//	lidar_begin();
//	HAL_UART_Receive_DMA(&huart4, g_raw_data, BUFFER_SIZE);
//
//	// Initialisation du LIDAR
//	lidar_end();
//	lidar_query_status();
//	lidar_check_health();
//
//
//	// Création de la tâche LIDAR
//	ret = xTaskCreate(TaskLIDAR, "TaskLIDAR", STACK_SIZE,
//			(void *) NULL, 1, &xHandleSensor);// Tache Neutralisée car asser en angle pas fonctionnel
//	if (ret != pdPASS)
//	{
//		printf("Error creating TaskSensor\r\n");
//		Error_Handler();
//	}
//
//
//	// Création des sémaphores pour la synchronisation DMA
//	SemHalfCallBack = xSemaphoreCreateBinary();
//	SemClpCallBack = xSemaphoreCreateBinary();
	init_motors();

	//I2C_Scan();


	VL53L1__Init();
	printf("Initialisation du système STM32 terminée.\n");

	VL53L1X_StartRanging(TOF_ADDR); // Démarrer le capteur
	VL53L1X_SetDistanceThreshold(TOF_ADDR, 10, 250, 1, 0); // Définir le seuil de distance
	VL53L1X_SetInterruptPolarity(TOF_ADDR, 1); // Configurer la polarité de l'interruption
	VL53L1X_ClearInterrupt(TOF_ADDR); // Effacer les interruptions en attente


	// Créer les tâches FreeRTOS
	xTaskCreate(vTaskADX, "TaskADX", 256, NULL, 2, NULL);
	xTaskCreate(vTaskToF, "TaskToF", 256, NULL, 5, NULL);
	//xTaskCreate(TaskLIDAR, "TaskLIDAR", 256, NULL, 5, NULL);


	//xTaskCreate(task_Bord, "Bord", 128, NULL, 8, &h_task_bord);
	//xTaskCreate(task_SensorMeasurement, "SensorMeasurement", 256, NULL, 4, NULL);








	/* USER CODE END 2 */

	/* Call init function for freertos objects (in cmsis_os2.c) */
	MX_FREERTOS_Init();

	/* Start scheduler */
	osKernelStart();

	/* We should never get here as control is now taken by the scheduler */

	/* Infinite loop */
	/* USER CODE BEGIN WHILE */





	while (1)
	{

		//uint16_t distance;
		// Lecture de la distance avec vérification d'erreur
		/*if (VL53L1X_GetDistance(TOF_ADDR, &distance) == 0) {
		   printf("Distance mesurée : %d mm\n", distance);
		   } else {
		   printf("Erreur lors de la mesure.\n");
		   }*/

		//VL53L1__test();

		HAL_Delay(500);



		/* USER CODE END WHILE */

		/* USER CODE BEGIN 3 */
	}
	/* USER CODE END 3 */
}

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
/* USER CODE BEGIN 4 */
void HAL_UART_RxHalfCpltCallback(UART_HandleTypeDef *huart)
{
	BaseType_t xHigherPriorityTaskWoken = pdFALSE;
	xSemaphoreGiveFromISR(SemHalfCallBack, &xHigherPriorityTaskWoken);
	portYIELD_FROM_ISR(xHigherPriorityTaskWoken);
}

void HAL_UART_RxCpltCallback(UART_HandleTypeDef *huart)
{
	BaseType_t xHigherPriorityTaskWoken = pdFALSE;
	xSemaphoreGiveFromISR(SemClpCallBack, &xHigherPriorityTaskWoken);
	portYIELD_FROM_ISR(xHigherPriorityTaskWoken);
}

void HAL_GPIO_EXTI_Callback(uint16_t GPIO_Pin)
{
	if (GPIO_Pin == INT_TOF2_Pin) {
		printf("Interruption détectée sur le capteur TOF.\n");

		// Effacer l'interruption immédiatement
		VL53L1X_ClearInterrupt(TOF_ADDR);
	}
}

/*void HAL_GPIO_EXTI_Callback(uint16_t GPIO_Pin)
{
	VL53L1X_ClearInterrupt(TOF_ADDR);
	printf("Tu tombe \n") ;
	VL53L1X_ClearInterrupt(TOF_ADDR);

}*/
/* USER CODE END 4 */

/**
 * @brief  Period elapsed callback in non blocking mode
 * @note   This function is called  when TIM6 interrupt took place, inside
 * HAL_TIM_IRQHandler(). It makes a direct call to HAL_IncTick() to increment
 * a global variable "uwTick" used as application time base.
 * @param  htim : TIM handle
 * @retval None
 */
void HAL_TIM_PeriodElapsedCallback(TIM_HandleTypeDef *htim)
{
	if (htim->Instance == TIM6) {
		HAL_IncTick();
	}
}

/**
 * @brief  This function is executed in case of error occurrence.
 * @retval None
 */
void Error_Handler(void)
{
	/* USER CODE BEGIN Error_Handler_Debug */
	/* User can add his own implementation to report the HAL error return state */
	__disable_irq();
	while (1)
	{
	}
	/* USER CODE END Error_Handler_Debug */
}


#ifdef  USE_FULL_ASSERT
/**
 * @brief  Reports the name of the source file and the source line number
 *         where the assert_param error has occurred.
 * @param  file: pointer to the source file name
 * @param  line: assert_param error line source number
 * @retval None
 */
void assert_failed(uint8_t *file, uint32_t line)
{
	/* USER CODE BEGIN 6 */
	/* User can add his own implementation to report the file name and line number,
     ex: printf("Wrong parameters value: file %s on line %d\r\n", file, line) */
	/* USER CODE END 6 */
}
#endif /* USE_FULL_ASSERT */

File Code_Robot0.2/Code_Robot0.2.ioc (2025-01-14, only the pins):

Mcu.UserName=STM32G431CBUx
PA1.GPIO_Label=LIDAR M_EN
PA1.Signal=GPIO_Output
PA10.GPIO_Label=LIDAR M_SCTR
PA10.Signal=S_TIM1_CH3
PA11.GPIO_Label=PWM_MOT1_CH1N
PA11.Signal=TIM1_CH1N
PA12.GPIO_Label=PWM_MOT2_CH2N
PA12.Signal=TIM1_CH2N
PA13.Signal=SYS_JTMS-SWDIO
PA14.Signal=SYS_JTCK-SWCLK
PA15.GPIO_Label=Status_Lidar
PA15.Signal=GPIO_Output
PA2.GPIO_Label=TX_link (stlink)
PA2.Signal=USART2_TX
PA3.GPIO_Label=RX_link (stlink)
PA3.Signal=USART2_RX
PA4.GPIO_Label=LIDAR DEV_EN
PA4.Signal=GPIO_Output
PA5.Signal=SPI1_SCK
PA6.Signal=SPI1_MISO
PA7.Signal=SPI1_MOSI
PA8.GPIO_Label=PWM_MOT1_CH1
PA8.Signal=S_TIM1_CH1
PA9.GPIO_Label=PWM_MOT2_CH2
PA9.Signal=S_TIM1_CH2
PB1.GPIO_Label=INT1_ADX
PB1.Signal=GPXTI1
PB13.GPIO_Label=Status_Blue
PB13.Signal=GPIO_Output
PB14.GPIO_Label=Status_Red
PB14.Signal=GPIO_Output
PB15.Signal=GPXTI15
PB2.GPIO_Label=INT2_ADX
PB2.Signal=GPXTI2
PB4.GPIO_Label=Codeur1_PH1
PB4.Signal=S_TIM3_CH1
PB5.GPIO_Label=Codeur1_PH2
PB5.Signal=S_TIM3_CH2
PB6.GPIO_Label=Codeur2_PH1
PB6.Signal=S_TIM4_CH1
PB7.GPIO_Label=Codeur2_PH2
PB7.Signal=S_TIM4_CH2
PB8-BOOT0.GPIO_Label=SCL_TOF
PB8-BOOT0.Signal=I2C1_SCL
PB9.GPIO_Label=SDA_TOF
PB9.Signal=I2C1_SDA
PC10.GPIO_Label=TX_LIDAR
PC10.Signal=UART4_TX
PC11.GPIO_Label=RX_LIDAR
PC11.Signal=UART4_RX
PC14-OSC32_IN.GPIO_Label=INT_TOF2
PC14-OSC32_IN.Signal=GPXTI14
PC4.GPIO_Label=SPI1_NSS
PC4.Signal=GPIO_Output
PF0-OSC_IN.Signal=RCC_OSC_IN
PF1-OSC_OUT.Signal=RCC_OSC_OUT

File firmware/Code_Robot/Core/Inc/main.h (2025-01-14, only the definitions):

#define INT_TOF2_Pin GPIO_PIN_14
#define INT_TOF2_GPIO_Port GPIOC
#define INT_TOF2_EXTI_IRQn EXTI15_10_IRQn
#define LIDAR_M_EN_Pin GPIO_PIN_1
#define LIDAR_M_EN_GPIO_Port GPIOA
#define TX_link_Pin GPIO_PIN_2
#define TX_link_GPIO_Port GPIOA
#define RX_link_Pin GPIO_PIN_3
#define RX_link_GPIO_Port GPIOA
#define LIDAR_DEV_EN_Pin GPIO_PIN_4
#define LIDAR_DEV_EN_GPIO_Port GPIOA
#define SPI1_NSS_Pin GPIO_PIN_4
#define SPI1_NSS_GPIO_Port GPIOC
#define INT1_ADX_Pin GPIO_PIN_1
#define INT1_ADX_GPIO_Port GPIOB
#define INT1_ADX_EXTI_IRQn EXTI1_IRQn
#define INT2_ADX_Pin GPIO_PIN_2
#define INT2_ADX_GPIO_Port GPIOB
#define INT2_ADX_EXTI_IRQn EXTI2_IRQn
#define Status_Blue_Pin GPIO_PIN_13
#define Status_Blue_GPIO_Port GPIOB
#define Status_Red_Pin GPIO_PIN_14
#define Status_Red_GPIO_Port GPIOB
#define PWM_MOT1_CH1_Pin GPIO_PIN_8
#define PWM_MOT1_CH1_GPIO_Port GPIOA
#define PWM_MOT2_CH2_Pin GPIO_PIN_9
#define PWM_MOT2_CH2_GPIO_Port GPIOA
#define LIDAR_M_SCTR_Pin GPIO_PIN_10
#define LIDAR_M_SCTR_GPIO_Port GPIOA
#define PWM_MOT1_CH1N_Pin GPIO_PIN_11
#define PWM_MOT1_CH1N_GPIO_Port GPIOA
#define PWM_MOT2_CH2N_Pin GPIO_PIN_12
#define PWM_MOT2_CH2N_GPIO_Port GPIOA
#define Status_Lidar_Pin GPIO_PIN_15
#define Status_Lidar_GPIO_Port GPIOA
#define TX_LIDAR_Pin GPIO_PIN_10
#define TX_LIDAR_GPIO_Port GPIOC
#define RX_LIDAR_Pin GPIO_PIN_11
#define RX_LIDAR_GPIO_Port GPIOC
#define Codeur1_PH1_Pin GPIO_PIN_4
#define Codeur1_PH1_GPIO_Port GPIOB
#define Codeur1_PH2_Pin GPIO_PIN_5
#define Codeur1_PH2_GPIO_Port GPIOB
#define Codeur2_PH1_Pin GPIO_PIN_6
#define Codeur2_PH1_GPIO_Port GPIOB
#define Codeur2_PH2_Pin GPIO_PIN_7
#define Codeur2_PH2_GPIO_Port GPIOB
#define SCL_TOF_Pin GPIO_PIN_8
#define SCL_TOF_GPIO_Port GPIOB
#define SDA_TOF_Pin GPIO_PIN_9
#define SDA_TOF_GPIO_Port GPIOB

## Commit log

2024-09-25 schématique bien avancé
    [StealthKitty.kicad_pcb, StealthKitty.kicad_sch, brain.kicad_sch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]
2024-10-01 psuh sur le main après revue prof
    [StealthKitty.kicad_pro.kicad_pcb, StealthKitty.kicad_pro.kicad_sch, brain.kicad_sch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]
2024-10-01 Supprimer le répertoire pcb_chat_wawa et ses fichiers
    [ADXL343BCCZ-RL.SchLib, ADXL343BCCZ-RL.stp, ADXL343BCCZRL.PcbLib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]
2024-10-01 Ajout des tâches à se partager
2024-10-01 Ajout des tâches à se partager v2
2024-10-01 Modif karim
    [StealthKitty.kicad_pro.kicad_sch, power.kicad_sch]
2024-10-03 réassignation pins stm32, ajout des modifs de la partie power, ajout des modfis de la revue de projet 02/10/24, modifs du 3/10/24 voir readme
    [StealthKitty.kicad_pro.kicad_sch, brain.kicad_sch, motorisation.kicad_sch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]
2024-10-03 suppression sous feuille 6,suppression dossier stealthkitty présent dans /hardware
    [StealthKitty.kicad_pro.kicad_pcb, StealthKitty.kicad_pro.kicad_sch]
2024-10-07 MAJ routage equipe
    [StealthKitty.kicad_pro.kicad_pcb, StealthKitty.kicad_pro.kicad_sch, brain.kicad_sch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]
2024-10-07 Confirmation placement equipe
    [StealthKitty.kicad_pro.kicad_pcb, brain.kicad_sch, motorisation.kicad_sch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]
2024-10-08 après première revue fiack placement
    [StealthKitty.kicad_pro.kicad_pcb, StealthKitty.kicad_pro.kicad_sch, brain.kicad_sch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]
2024-10-08 Update README.md
    carnet de bord
2024-10-08 Dernier Modif 08/10/2024
    [StealthKitty.kicad_pro.kicad_pcb, brain.kicad_sch, motorisation.kicad_sch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]
2024-10-09 readme avant push des autres
2024-10-09 Modification Placement 09/10/24
    [StealthKitty.kicad_pro.kicad_pcb, power.kicad_sch, sensor.kicad_sch]
2024-10-09 Début routage
    [StealthKitty.kicad_pro.kicad_pcb]
2024-10-09 MAJ première version routage
    [StealthKitty.kicad_pro.kicad_pcb, StealthKitty.kicad_pro.kicad_sch, brain.kicad_sch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]
2024-10-09 Ajout de README
2024-10-09 Modif Routage V2
    [StealthKitty.kicad_pro.kicad_pcb, StealthKitty.kicad_pro.kicad_sch, brain.kicad_sch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]
2024-10-10 Modif Routage V3
    [StealthKitty.kicad_pro.kicad_pcb]
2024-10-10 Dernier Modif ROUTAGE 10/10/24
    [StealthKitty.kicad_pro.kicad_pcb]
2024-10-15 Amélioration de la partie routage
    [StealthKitty.kicad_pro.kicad_pcb]
2024-10-16 Modif PCB 16/10/2024 V1
    [Review 1.xlsx, brain.kicad_sch, power.kicad_sch]
2024-10-16 Modif PCB 16/10/2024 V2
    [Review 1.xlsx, StealthKitty.kicad_pro.kicad_pcb, brain.kicad_sch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]
2024-10-17 Modif PCB 17/10/2024 V3
    [StealthKitty.kicad_pro.kicad_pcb]
2024-10-17 Routage final pour vérification prof
    [StealthKitty.kicad_pro.kicad_pcb]
2024-10-22 MODIF PCB 22/10/2024
    [StealthKitty.kicad_pro.kicad_pcb, brain.kicad_sch]
2024-10-22 Modif après revue du prof le 22/10
    [StealthKitty.kicad_pro.kicad_pcb, StealthKitty.kicad_pro.kicad_sch, brain.kicad_sch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]
2024-10-23 Ajout fichier GERBER
    [StealthKitty.kicad_pro-B_Cu.gbr, StealthKitty.kicad_pro-B_Mask.gbr, StealthKitty.kicad_pro-B_Paste.gbr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]
2024-10-23 Ajout fichier GERBER zip
2024-10-23 Ajout fichier GERBER final
    [StealthKitty.kicad_pro-B_Cu.gbr, StealthKitty.kicad_pro-B_Mask.gbr, StealthKitty.kicad_pro-B_Paste.gbr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]
2024-10-23 readme spi adx
2024-10-23 Dernier Modif 23/10/2024
    [StealthKitty.kicad_pro.kicad_pcb, StealthKitty.kicad_pro.kicad_sch, brain.kicad_sch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]
2024-10-23 Regeneration fichier Gerber après ajustement zone pastemask
    [StealthKitty.kicad_pro-B_Cu.gbr, StealthKitty.kicad_pro-B_Mask.gbr, StealthKitty.kicad_pro-B_Paste.gbr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]
2024-12-16 MAJ Code accelerometre
2025-01-07 démarrage des moteurs avec rapport cyclique de 50% incohérent
2025-01-14 Rename image-20250114113650516.png to driver motor- image-20250114113650516.png
2025-01-14 Rename image-lidar-20250114095520915.png to lidar -image-lidar-20250114095520915.png
